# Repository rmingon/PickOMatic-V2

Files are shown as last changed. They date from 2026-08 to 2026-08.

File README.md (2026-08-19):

# PickOMatic V2

> **Place faster. Place smarter. The open-source motion controller that turns your pick-and-place ambitions into production reality.**

<p align="center">
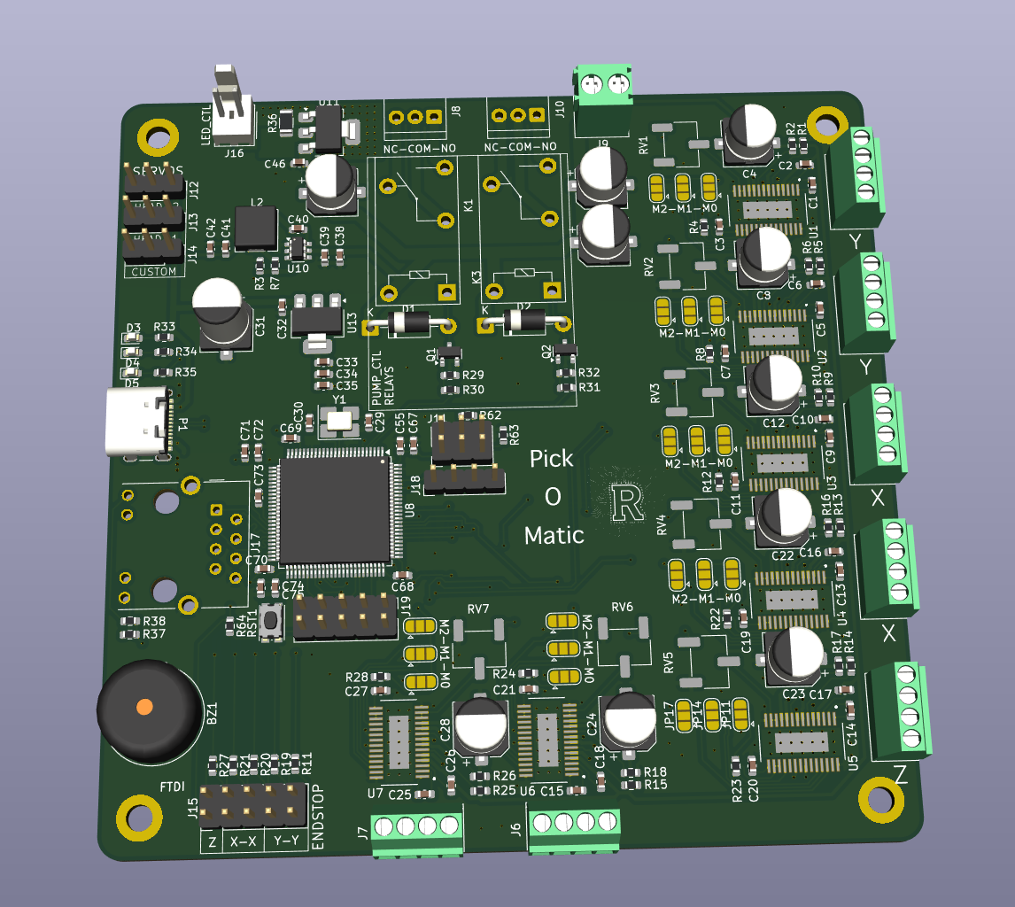
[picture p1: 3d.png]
PickOMatic V2 board, 3D render
  
</p>

<p align="center">
  
  
  
  
</p>

---

**PickOMatic V2** is a professional-grade, all-in-one motion control board designed from the ground up for desktop pick-and-place machines. It is the second generation of the [PickOMatic](https://github.com/rmingon/PickOMatic) motion controller, rebuilt around a modern 32-bit **RISC-V** microcontroller with native **Ethernet** and **USB-C** connectivity.

One board drives the entire machine: gantry, picker heads, nozzles, vacuum, lighting and feedback, with no shields, no breakout spaghetti and no compromises.

## Highlights

- **RISC-V power** : WCH **CH32V317VCT6** (QingKe 32-bit RISC-V core, LQFP-100), a massive leap over the 8-bit ATmega2560 of V1
- **7 stepper channels** : on-board **DRV8825** drivers for the XY gantry, Z axis and auxiliary picker-head axes, each with per-channel microstepping selection (M0/M1/M2 solder jumpers) and current trim
- **Ethernet on board** : integrated PHY with RJ45 magjack (HR911105A) for fast, reliable G-code streaming over the network
- **USB-C** : modern connectivity for setup, control and firmware workflows
- **Vacuum and pneumatics** : dedicated relay outputs (NC-COM-NO) for the vacuum pump and pneumatic accessories
- **3 servo outputs** : independent nozzle height / rotation control per picker head
- **5 endstop inputs** : dedicated limit-switch inputs for X, Y and Z homing (dual X and dual Y supported)
- **Inspection lighting** : dedicated LED control output for camera lighting
- **Operator feedback** : on-board buzzer and status LEDs
- **Expansion ready** : I²C bus, custom headers, FTDI UART header, SWD debug port and BOOT jumpers
- **Clean power architecture** : single 12 V input with on-board buck converters (TPS562200) and LDO rails for logic

## What's new in V2

| | PickOMatic V1 | **PickOMatic V2** |
|---|---|---|
| Microcontroller | ATmega2560 @ 16 MHz (8-bit AVR) | **CH32V317VCT6 (32-bit RISC-V)** |
| Host link | USB-UART (CH340C) | **Native USB-C + Ethernet (RJ45)** |
| Stepper channels | 8 | 7 x DRV8825 with per-axis microstep jumpers |
| Debug / programming | AVR-ISP | **SWD + FTDI UART + BOOT jumpers** |
| Networking | None | **On-board Ethernet PHY + magjack** |

## Board overview

| PCB layout | Schematic |
|:---:|:---:|
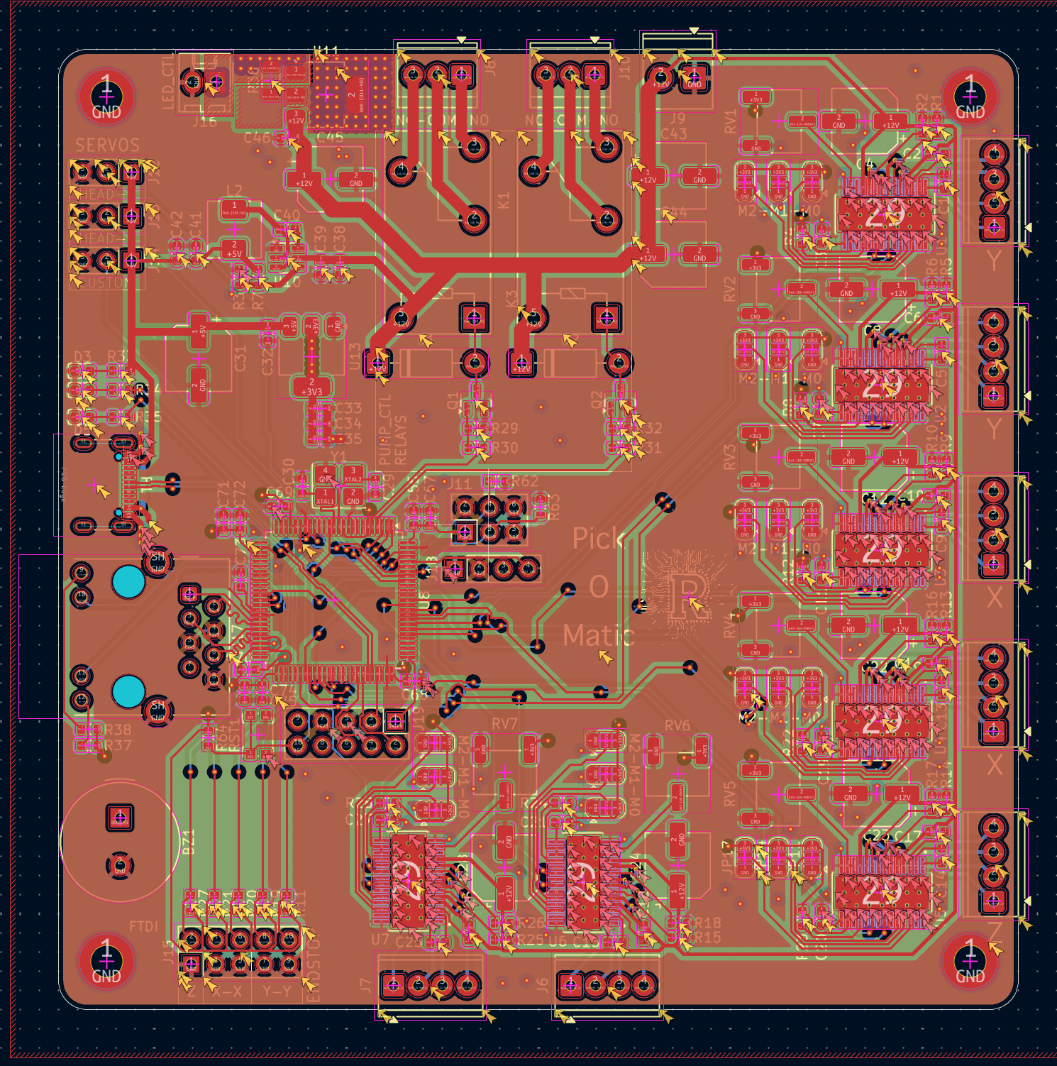
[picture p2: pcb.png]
PCB layout
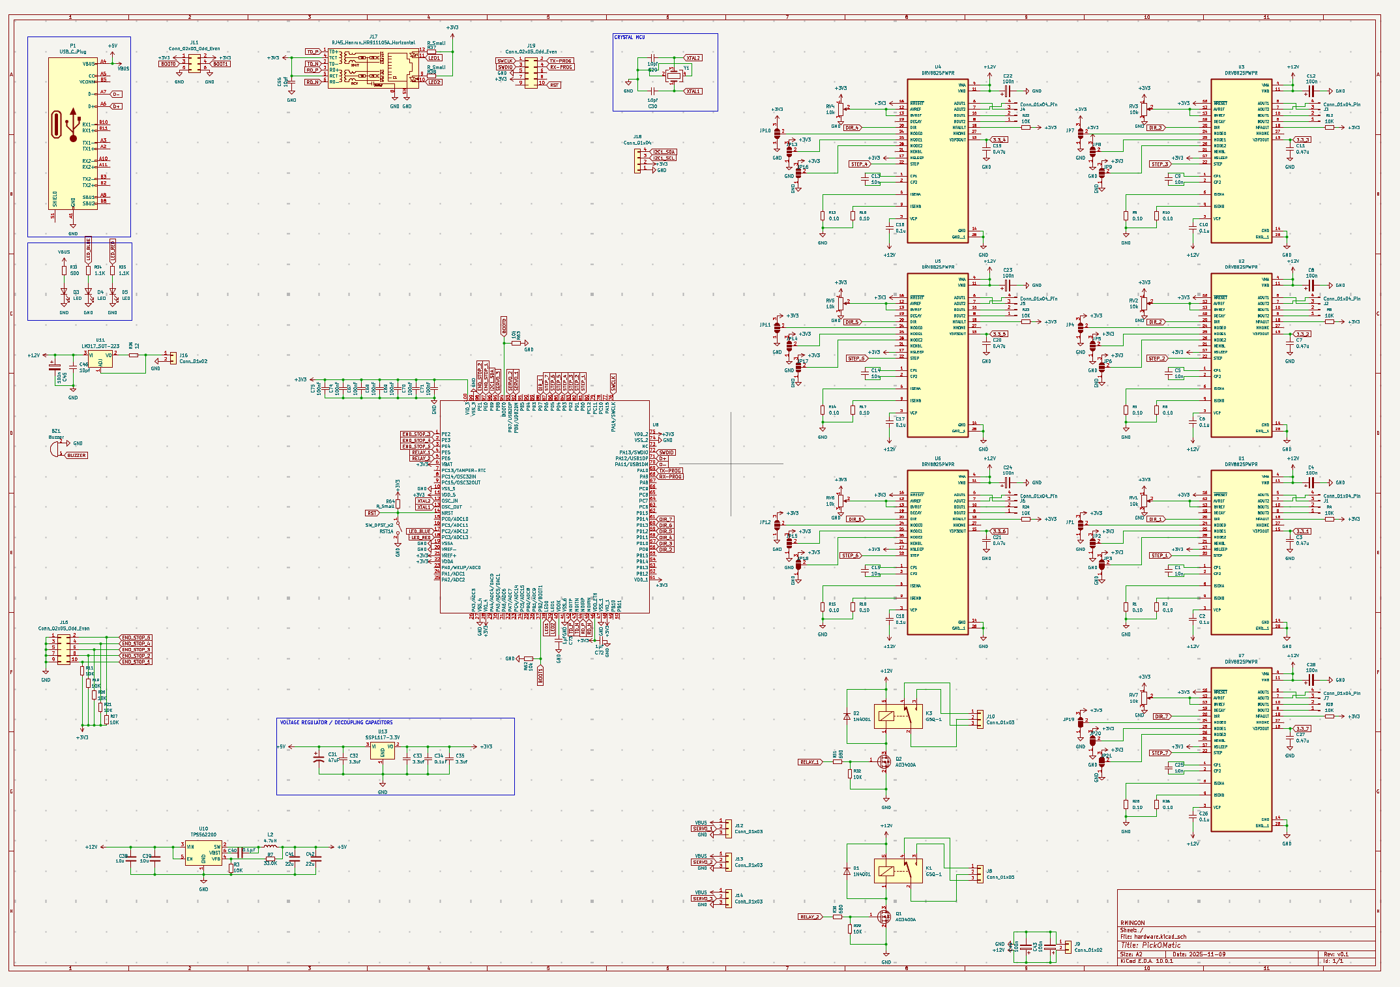
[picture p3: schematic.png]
Schematic
|  |  |

## Specifications

| Subsystem | Detail |
|---|---|
| MCU | WCH CH32V317VCT6, 32-bit RISC-V, LQFP-100, external crystal |
| Motion | 7 x DRV8825 stepper drivers (STEP/DIR), microstepping via M0/M1/M2 solder jumpers, current trim potentiometers |
| Axes | Dual-Y and dual-X gantry support, Z axis, auxiliary picker-head channels |
| Endstops | 5 inputs (Z, X-X, Y-Y) on a dedicated header |
| Servos | 3 PWM outputs for nozzle actuation |
| Pneumatics | Relay outputs with NC-COM-NO terminals for vacuum pump control |
| Lighting | Dedicated LED_CTL output for inspection lighting |
| Connectivity | USB-C, 10M Ethernet (RJ45 HR911105A), I²C expansion, FTDI UART |
| Debug | SWD (SWCLK/SWDIO), BOOT0/BOOT1 jumpers, reset button |
| Feedback | Buzzer, status LEDs |
| Power input | 12 V DC via screw terminal |
| Power rails | 12 V motor rail, 5 V and 3.3 V logic rails (TPS562200 buck converters + LDOs) |
| Form factor | 4-corner mounting holes, screw-terminal I/O on board edges |

## Repository structure

```
PickOMatic-V2/
├── hardware/               # KiCad project (schematic + PCB)
│   ├── hardware.kicad_pro
│   ├── hardware.kicad_sch
│   └── hardware.kicad_pcb
├── 3d.png                  # 3D render of the assembled board
├── pcb.png                 # PCB layout view
├── schematic.png           # Full schematic
├── LICENSE                 # CERN-OHL-S v2
└── README.md
```

## Getting started

1. **Clone** the repository
   ```bash
   git clone https://github.com/rmingon/PickOMatic-V2.git
   ```
2. **Open** `hardware/hardware.kicad_pro` in [KiCad](https://www.kicad.org/) (version 8 or later recommended)
3. **Review** the schematic and PCB, then export Gerbers and the BOM for your fab house
4. **Assemble**, set the DRV8825 current limits, configure microstepping with the solder jumpers, and connect your motors, endstops, servos and vacuum pump
5. **Flash** your firmware via SWD or the FTDI/BOOT bootloader path, and start placing parts

## Related projects

- [PickOMatic (V1)](https://github.com/rmingon/PickOMatic) : the original ATmega2560-based motion controller this board evolved from

## Contributing

Issues and pull requests are welcome. If you build a machine around PickOMatic V2, share it: photos, firmware ports and feeder designs all help the project grow.

## License

This project is open-source hardware, released under the **CERN Open Hardware Licence Version 2, Strongly Reciprocal (CERN-OHL-S-2.0)**.

You may use, study, modify, manufacture and distribute this design, provided that any modified versions are released under the same licence and that source is made available. See [LICENSE](LICENSE) for the full text.

Copyright © 2026 [rmingon](https://github.com/rmingon)

---

<p align="center"><i>PickOMatic V2, because your components deserve to be placed with confidence.</i></p>

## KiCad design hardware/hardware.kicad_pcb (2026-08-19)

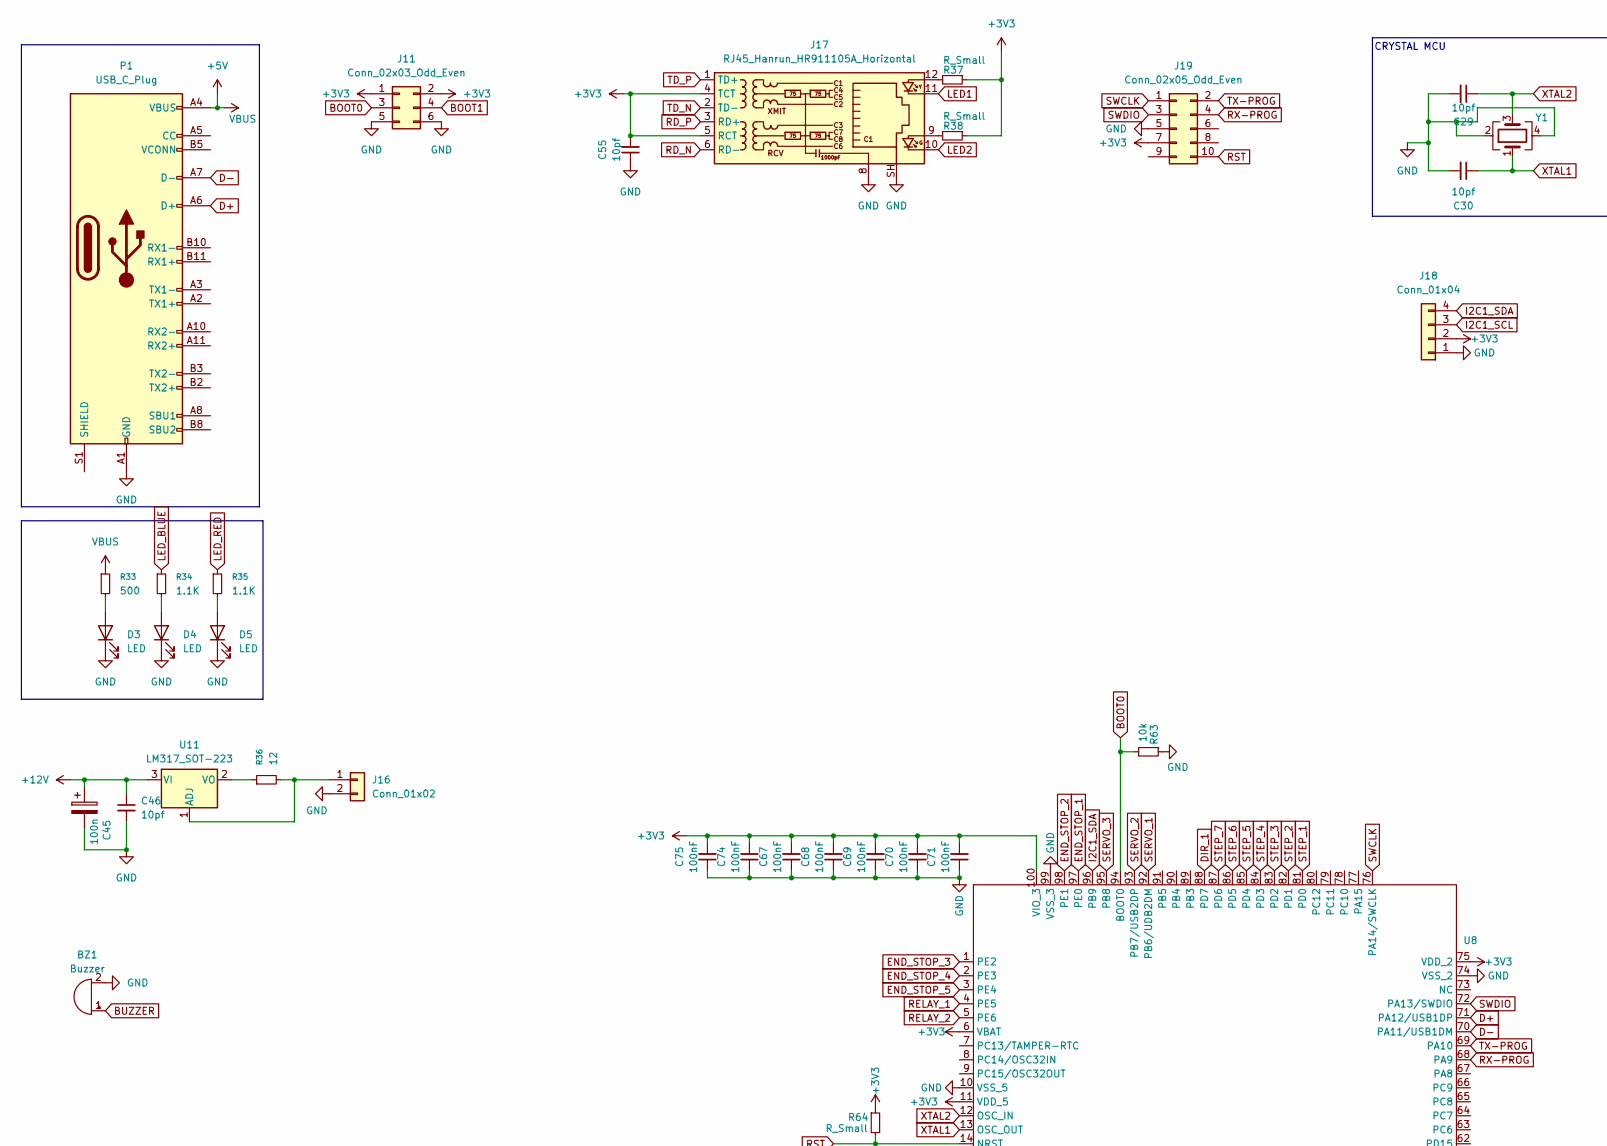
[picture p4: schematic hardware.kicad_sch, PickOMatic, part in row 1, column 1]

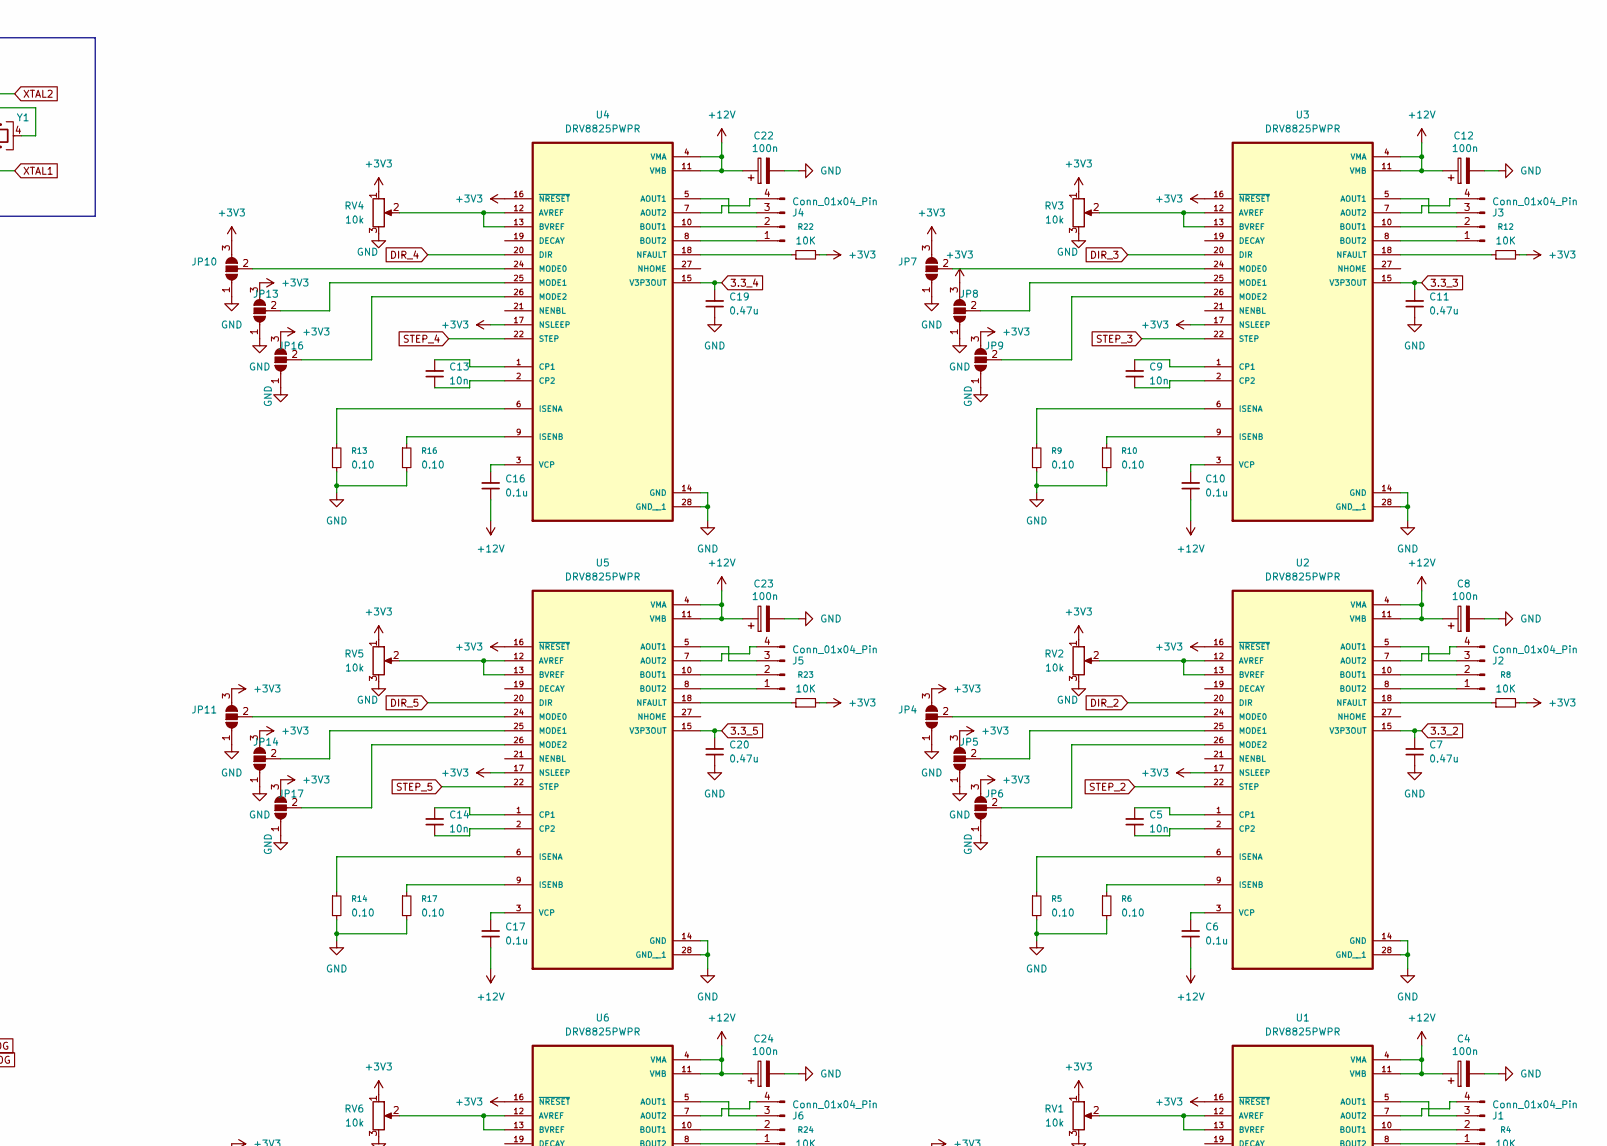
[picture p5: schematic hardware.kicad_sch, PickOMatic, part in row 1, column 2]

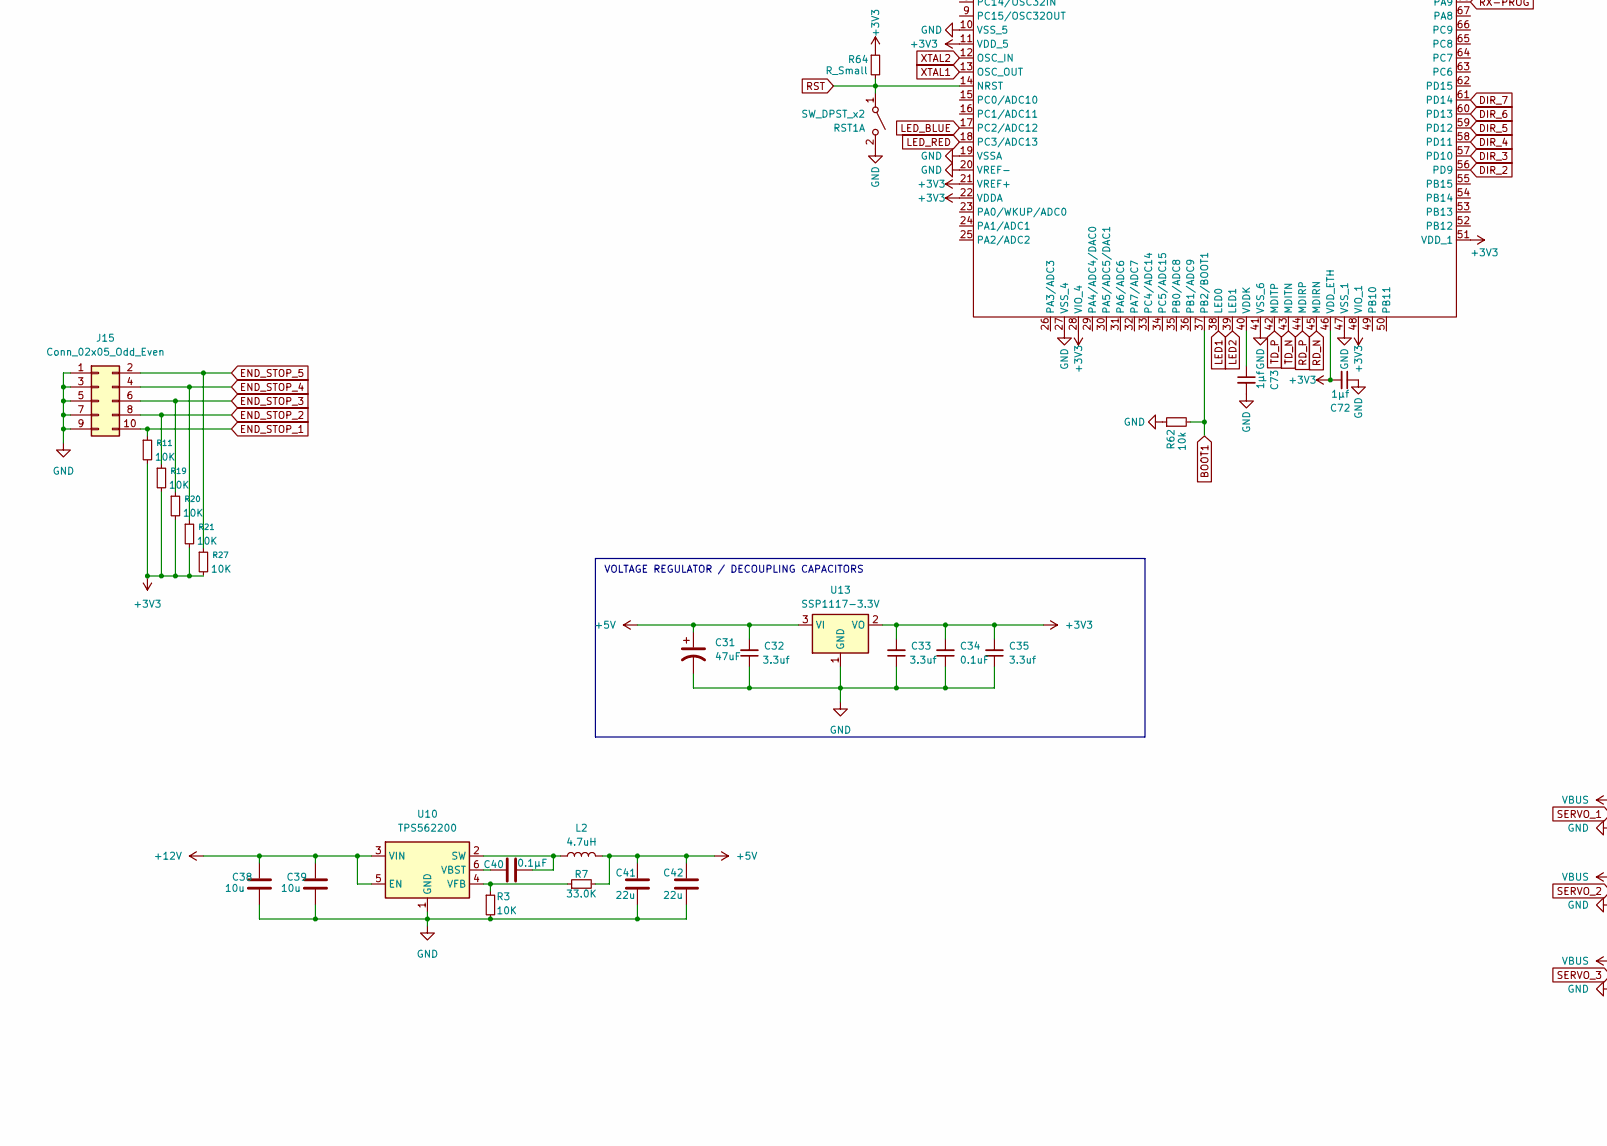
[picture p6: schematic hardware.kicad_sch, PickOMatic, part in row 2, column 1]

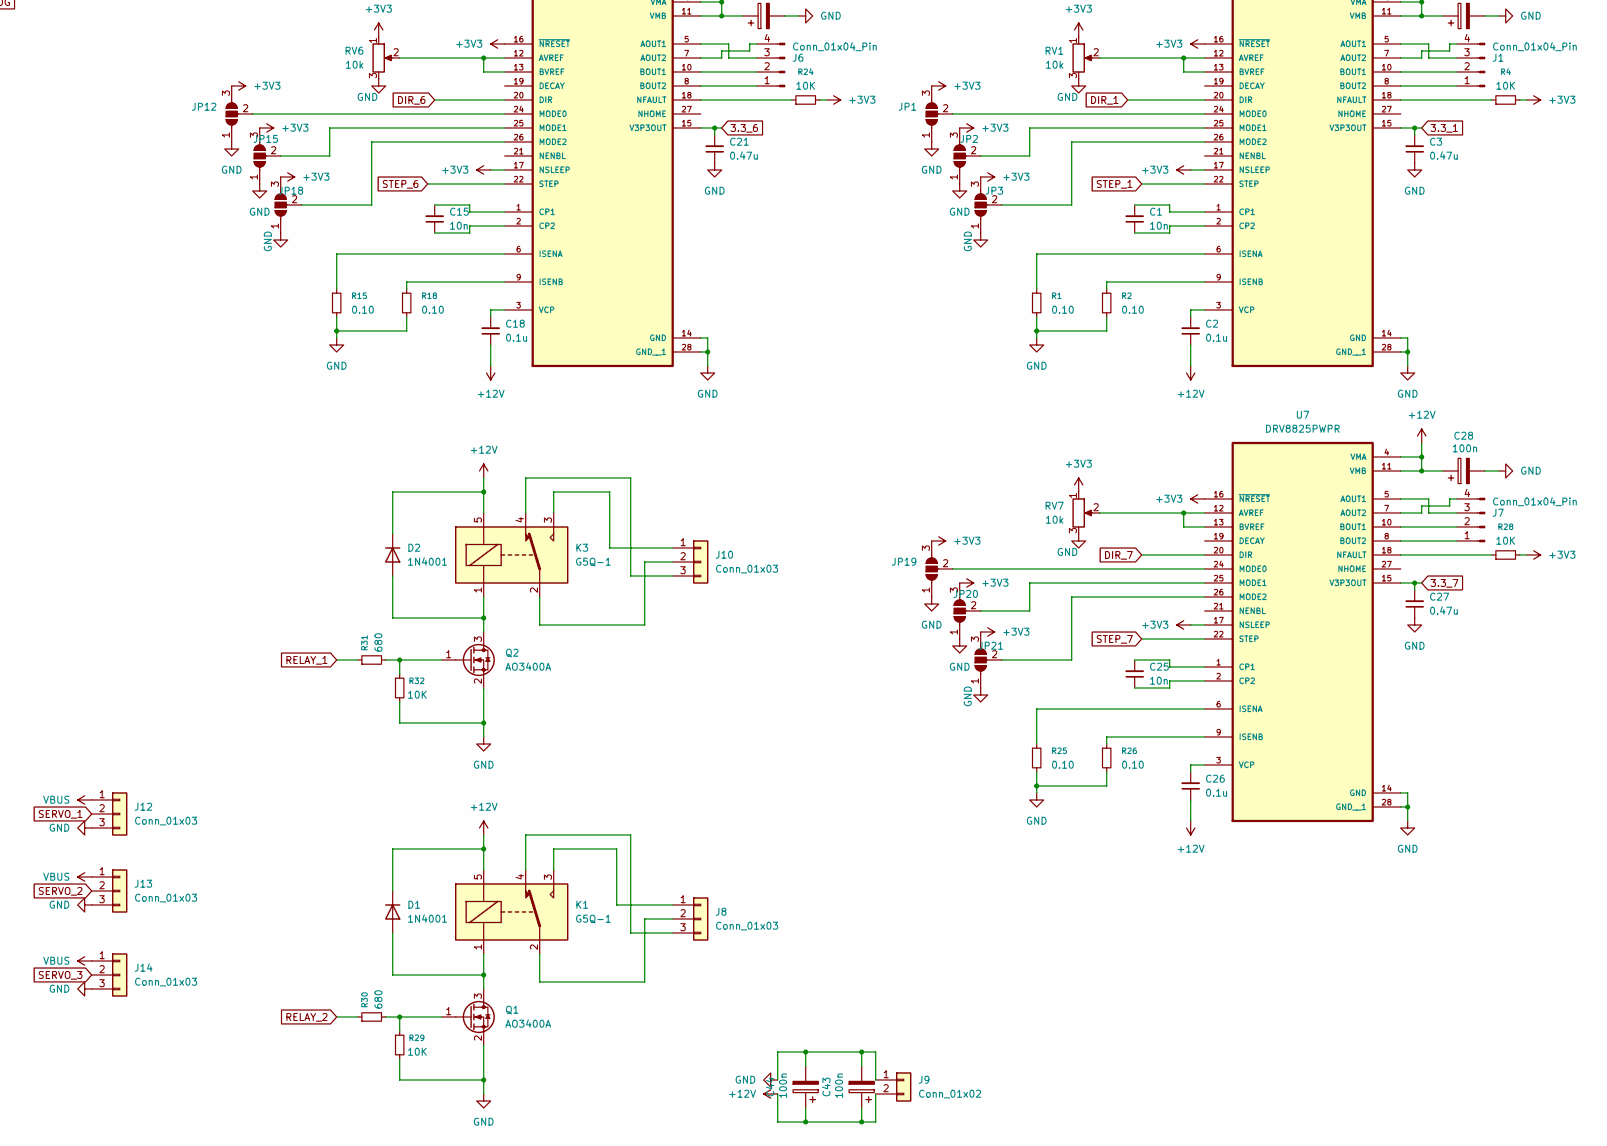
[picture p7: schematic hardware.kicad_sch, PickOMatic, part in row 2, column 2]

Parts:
BZ1: Buzzer; Buzzer_TDK_PS1240P02BT_D12.2mm_H6.5mm
C1, C5, C9, C13, C14, C15, C25: 10n; C_0603_1608Metric
C2, C6, C10, C16, C17, C18, C26: 0.1u; C_0603_1608Metric
C3, C7, C11, C19, C20, C21, C27: 0.47u; C_0603_1608Metric
C4, C8, C12, C22, C23, C24, C28, C43, C44, C45: 100n; CP_Elec_6.3x5.7
C29, C30, C46, C55: 10pf; C_0603_1608Metric; LCSC C106245
C31: 47uF; CP_Elec_6.3x9.9; LCSC C3032930
C32, C33, C35: 3.3uf; C_0603_1608Metric; LCSC C51412
C34: 0.1uF; C_0603_1608Metric; LCSC C14663
C38, C39: 10u; C_0603_1608Metric; LCSC C1691
C40: 0.1µF; C_0603_1608Metric; LCSC C6119867
C41, C42: 22u; C_0603_1608Metric; LCSC C6119867
C67, C68, C69, C70, C71, C74, C75: 100nF; C_0603_1608Metric; LCSC C106245
C72, C73: 1µf; C_0603_1608Metric; LCSC C106245
D1, D2: 1N4001; D_DO-41_SOD81_P10.16mm_Horizontal
D3, D4, D5: LED; LED_0603_1608Metric
J1, J2, J3, J4, J5, J6, J7: Conn_01x04_Pin; TerminalBlock_Phoenix_MPT-0,5-4-2.54_1x04_P2.54mm_Horizontal
J8, J10: Conn_01x03; TerminalBlock_TE_282834-3_1x03_P2.54mm_Horizontal
J9: Conn_01x02; TerminalBlock_Phoenix_PT-1,5-2-3.5-H_1x02_P3.50mm_Horizontal
J11: Conn_02x03_Odd_Even; PinHeader_2x03_P2.54mm_Vertical
J12, J13, J14: Conn_01x03; PinHeader_1x03_P2.54mm_Vertical
J15, J19: Conn_02x05_Odd_Even; PinHeader_2x05_P2.54mm_Vertical
J16: Conn_01x02; Molex_KK-254_AE-6410-02A_1x02_P2.54mm_Vertical
J17: RJ45_Hanrun_HR911105A_Horizontal
J18: Conn_01x04; PinHeader_1x04_P2.54mm_Vertical
JP1, JP2, JP3, JP4, JP5, JP6, JP7, JP8, JP9, JP10, JP11, JP12, JP13, JP14, JP15, JP16, JP17, JP18, JP19, JP20, JP21: SolderJumper_3_Open; SolderJumper-3_P1.3mm_Open_RoundedPad1.0x1.5mm
K1, K3: G5Q-1; Relay_SPDT_Omron-G5Q-1
L2: 4.7uH; L_Chilisin_BMRA00050520; LCSC C3002619
P1: USB_C_Plug; USB_C_Receptacle_GCT_USB4105-xx-A_16P_TopMnt_Horizontal
Q1, Q2: AO3400A; SOT-23
R1, R2, R5, R6, R9, R10, R13, R14, R15, R16, R17, R18, R25, R26: 0.10; R_0603_1608Metric
R3: 10K; R_0603_1608Metric; LCSC C25804
R4, R8, R11, R12, R19, R20, R21, R22, R23, R24, R27, R28, R29, R32: 10K; R_0603_1608Metric
R7: 33.0K; R_0603_1608Metric; LCSC C4216
R30, R31: 680; R_0603_1608Metric
R33: 500; R_0603_1608Metric
R34, R35: 1.1K; R_0603_1608Metric
R36: 12; R_1206_3216Metric
R37, R38, R64: R_Small; R_0603_1608Metric
R62, R63: 10k; R_0603_1608Metric
RST1: SW_DPST_x2; SW_Push_1P1T_NO_CK_KMR2
RV1, RV2, RV3, RV4, RV5, RV6, RV7: 10k; Potentiometer_Bourns_3269W_Vertical
U1, U2, U3, U4, U5, U6, U7: DRV8825PWPR; IC_TPS61196PWPRQ1
U8: LQFP-100_14x14mm_P0.5mm
U10: TPS562200; SOT-23-6; LCSC C49757
U11: LM317_SOT-223; SOT-223-3_TabPin2
U13: SSP1117-3.3V; SOT-223-3_TabPin2; LCSC C277892
Y1: Crystal_GND24; Crystal_SMD_3225-4Pin_3.2x2.5mm_HandSoldering

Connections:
3.3_1: C3.2, U1.15 (V3P3OUT)
3.3_2: C7.2, U2.15 (V3P3OUT)
3.3_3: C11.2, U3.15 (V3P3OUT)
3.3_4: C19.2, U4.15 (V3P3OUT)
3.3_5: C20.2, U5.15 (V3P3OUT)
3.3_6: C21.2, U6.15 (V3P3OUT)
3.3_7: C27.2, U7.15 (V3P3OUT)
+3V3: C33.2, C34.2, C35.2, C55.2, C67.2, C68.2, C69.2, C70.2, C71.2, C72.2, C74.2, C75.2, J11.1, J11.2, J17.4 (TCT), J17.5 (RCT), J18.2, J19.7, JP1.3 (B), JP2.3 (B), JP3.3 (B), JP4.3 (B), JP5.3 (B), JP6.3 (B), JP7.3 (B), JP8.3 (B), JP9.3 (B), JP10.3 (B), JP11.3 (B), JP12.3 (B), JP13.3 (B), JP14.3 (B), JP15.3 (B), JP16.3 (B), JP17.3 (B), JP18.3 (B), JP19.3 (B), JP20.3 (B), JP21.3 (B), R4.2, R8.2, R11.2, R12.2, R19.2, R20.2, R21.2, R22.2, R23.2, R24.2, R27.2, R28.2, R37.1, R38.1, R64.1, RV1.1, RV2.1, RV3.1, RV4.1, RV5.1, RV6.1, RV7.1, U1.16 (~NRESET), U1.17 (NSLEEP), U2.16 (~NRESET), U2.17 (NSLEEP), U3.16 (~NRESET), U3.17 (NSLEEP), U4.16 (~NRESET), U4.17 (NSLEEP), U5.16 (~NRESET), U5.17 (NSLEEP), U6.16 (~NRESET), U6.17 (NSLEEP), U7.16 (~NRESET), U7.17 (NSLEEP), U8.6 (VBAT), U8.11 (VDD_5), U8.21 (VREF+), U8.22 (VDDA), U8.28 (VIO_4), U8.46 (VDD_ETH), U8.48 (VIO_1), U8.51 (VDD_1), U8.75 (VDD_2), U8.100 (VIO_3), U13.2 (VO)
+5V: C31.1, C32.2, C41.1, C42.1, J12.1, J13.1, J14.1, L2.2, P1.A4 (VBUS), P1.A9 (VBUS), P1.B4 (VBUS), P1.B9 (VBUS), R7.2, R33.1, U13.3 (VI)
+12V: C2.1, C4.1, C6.1, C8.1, C10.1, C12.1, C16.1, C17.1, C18.1, C22.1, C23.1, C24.1, C26.1, C28.1, C38.1, C39.1, C43.1, C44.1, C45.1, C46.1, D1.1 (K), D2.1 (K), J9.2, K1.5, K3.5, U1.4 (VMA), U1.11 (VMB), U2.4 (VMA), U2.11 (VMB), U3.4 (VMA), U3.11 (VMB), U4.4 (VMA), U4.11 (VMB), U5.4 (VMA), U5.11 (VMB), U6.4 (VMA), U6.11 (VMB), U7.4 (VMA), U7.11 (VMB), U10.3 (VIN), U10.5 (EN), U11.3 (VI)
BOOT0: J11.3, R63.2, U8.94 (BOOT0)
BOOT1: J11.4, R62.2, U8.37 (PB2/BOOT1)
BUZZER: BZ1.1 (+)
D+: P1.A6 (D+), U8.71 (PA12/USB1DP)
D-: P1.A7 (D-), U8.70 (PA11/USB1DM)
DIR_1: U1.20 (DIR), U8.88 (PD7)
DIR_2: U2.20 (DIR), U8.56 (PD9)
DIR_3: U3.20 (DIR), U8.57 (PD10)
DIR_4: U4.20 (DIR), U8.58 (PD11)
DIR_5: U5.20 (DIR), U8.59 (PD12)
DIR_6: U6.20 (DIR), U8.60 (PD13)
DIR_7: U7.20 (DIR), U8.61 (PD14)
END_STOP_1: J15.10, R11.1, U8.97 (PE0)
END_STOP_2: J15.8, R19.1, U8.98 (PE1)
END_STOP_3: J15.6, R20.1, U8.1 (PE2)
END_STOP_4: J15.4, R21.1, U8.2 (PE3)
END_STOP_5: J15.2, R27.1, U8.3 (PE4)
GND: BZ1.2 (-), C3.1, C4.2, C7.1, C8.2, C11.1, C12.2, C19.1, C20.1, C21.1, C22.2, C23.2, C24.2, C27.1, C28.2, C29.2, C30.2, C31.2, C32.1, C33.1, C34.1, C35.1, C38.2, C39.2, C41.2, C42.2, C43.2, C44.2, C45.2, C46.2, C55.1, C67.1, C68.1, C69.1, C70.1, C71.1, C72.1, C73.2, C74.1, C75.1, D3.1 (K), D4.1 (K), D5.1 (K), J9.1, J11.5, J11.6, J12.3, J13.3, J14.3, J15.1, J15.3, J15.5, J15.7, J15.9, J16.2, J17.8, J17.SH, J18.1, J19.5, JP1.1 (A), JP2.1 (A), JP3.1 (A), JP4.1 (A), JP5.1 (A), JP6.1 (A), JP7.1 (A), JP8.1 (A), JP9.1 (A), JP10.1 (A), JP11.1 (A), JP12.1 (A), JP13.1 (A), JP14.1 (A), JP15.1 (A), JP16.1 (A), JP17.1 (A), JP18.1 (A), JP19.1 (A), JP20.1 (A), JP21.1 (A), P1.A1 (GND), P1.A12 (GND), P1.B1 (GND), P1.B12 (GND), Q1.2 (S), Q2.2 (S), R1.2, R2.2, R3.2, R5.2, R6.2, R9.2, R10.2, R13.2, R14.2, R15.2, R16.2, R17.2, R18.2, R25.2, R26.2, R29.2, R32.2, R62.1, R63.1, RST1.2 (B), RV1.3, RV2.3, RV3.3, RV4.3, RV5.3, RV6.3, RV7.3, U1.14 (GND), U1.28 (GND__1), U2.14 (GND), U2.28 (GND__1), U3.14 (GND), U3.28 (GND__1), U4.14 (GND), U4.28 (GND__1), U5.14 (GND), U5.28 (GND__1), U6.14 (GND), U6.28 (GND__1), U7.14 (GND), U7.28 (GND__1), U8.10 (VSS_5), U8.19 (VSSA), U8.20 (VREF-), U8.27 (VSS_4), U8.41 (VSS_6), U8.47 (VSS_1), U8.74 (VSS_2), U8.99 (VSS_3), U10.1 (GND), U13.1 (GND), Y1.2, Y1.4
I2C1_SCL: J18.3
I2C1_SDA: J18.4, U8.96 (PB9)
LED1: J17.11, U8.38 (LED0)
LED2: J17.10, U8.39 (LED1)
LED_BLUE: R34.1, U8.17 (PC2/ADC12)
LED_RED: R35.1, U8.18 (PC3/ADC13)
unnamed: D1.2 (A), K1.1, Q1.3 (D)
unnamed: D2.2 (A), K3.1, Q2.3 (D)
unnamed: D3.2 (A), R33.2
unnamed: D4.2 (A), R34.2
unnamed: D5.2 (A), R35.2
unnamed: J1.1, U1.8 (BOUT2)
unnamed: J1.2, U1.10 (BOUT1)
unnamed: J1.3, U1.5 (AOUT1)
unnamed: J1.4, U1.7 (AOUT2)
unnamed: J2.1, U2.8 (BOUT2)
unnamed: J2.2, U2.10 (BOUT1)
unnamed: J2.3, U2.5 (AOUT1)
unnamed: J2.4, U2.7 (AOUT2)
unnamed: J3.1, U3.8 (BOUT2)
unnamed: J3.2, U3.10 (BOUT1)
unnamed: J3.3, U3.5 (AOUT1)
unnamed: J3.4, U3.7 (AOUT2)
unnamed: J4.1, U4.8 (BOUT2)
unnamed: J4.2, U4.10 (BOUT1)
unnamed: J4.3, U4.5 (AOUT1)
unnamed: J4.4, U4.7 (AOUT2)
unnamed: J5.1, U5.8 (BOUT2)
unnamed: J5.2, U5.10 (BOUT1)
unnamed: J5.3, U5.5 (AOUT1)
unnamed: J5.4, U5.7 (AOUT2)
unnamed: J6.1, U6.8 (BOUT2)
unnamed: J6.2, U6.10 (BOUT1)
unnamed: J6.3, U6.5 (AOUT1)
unnamed: J6.4, U6.7 (AOUT2)
unnamed: J7.1, U7.8 (BOUT2)
unnamed: J7.2, U7.10 (BOUT1)
unnamed: J7.3, U7.5 (AOUT1)
unnamed: J7.4, U7.7 (AOUT2)
unnamed: J8.1, K1.3
unnamed: J8.2, K1.2
unnamed: J8.3, K1.4
unnamed: J10.1, K3.3
unnamed: J10.2, K3.2
unnamed: J10.3, K3.4
unnamed: J16.1, R36.2, U11.1 (ADJ)
unnamed: J17.9, R38.2
unnamed: J17.12, R37.2
unnamed: JP1.2 (C), U1.24 (MODE0)
unnamed: JP2.2 (C), U1.25 (MODE1)
unnamed: JP3.2 (C), U1.26 (MODE2)
unnamed: JP4.2 (C), U2.24 (MODE0)
unnamed: JP5.2 (C), U2.25 (MODE1)
unnamed: JP6.2 (C), U2.26 (MODE2)
unnamed: JP7.2 (C), U3.24 (MODE0)
unnamed: JP8.2 (C), U3.25 (MODE1)
unnamed: JP9.2 (C), U3.26 (MODE2)
unnamed: JP10.2 (C), U4.24 (MODE0)
unnamed: JP11.2 (C), U5.24 (MODE0)
unnamed: JP12.2 (C), U6.24 (MODE0)
unnamed: JP13.2 (C), U4.25 (MODE1)
unnamed: JP14.2 (C), U5.25 (MODE1)
unnamed: JP15.2 (C), U6.25 (MODE1)
unnamed: JP16.2 (C), U4.26 (MODE2)
unnamed: JP17.2 (C), U5.26 (MODE2)
unnamed: JP18.2 (C), U6.26 (MODE2)
unnamed: JP19.2 (C), U7.24 (MODE0)
unnamed: JP20.2 (C), U7.25 (MODE1)
unnamed: JP21.2 (C), U7.26 (MODE2)
unnamed: Q1.1 (G), R29.1, R30.2
unnamed: Q2.1 (G), R31.2, R32.1
unnamed: RV1.2, U1.12 (AVREF), U1.13 (BVREF)
unnamed: C1.2, U1.1 (CP1)
unnamed: C1.1, U1.2 (CP2)
unnamed: R1.1, U1.6 (ISENA)
unnamed: R2.1, U1.9 (ISENB)
unnamed: R4.1, U1.18 (NFAULT)
unnamed: C2.2, U1.3 (VCP)
unnamed: RV2.2, U2.12 (AVREF), U2.13 (BVREF)
unnamed: C5.2, U2.1 (CP1)
unnamed: C5.1, U2.2 (CP2)
unnamed: R5.1, U2.6 (ISENA)
unnamed: R6.1, U2.9 (ISENB)
unnamed: R8.1, U2.18 (NFAULT)
unnamed: C6.2, U2.3 (VCP)
unnamed: RV3.2, U3.12 (AVREF), U3.13 (BVREF)
unnamed: C9.2, U3.1 (CP1)
unnamed: C9.1, U3.2 (CP2)
unnamed: R9.1, U3.6 (ISENA)
unnamed: R10.1, U3.9 (ISENB)
unnamed: R12.1, U3.18 (NFAULT)
unnamed: C10.2, U3.3 (VCP)
unnamed: RV4.2, U4.12 (AVREF), U4.13 (BVREF)
unnamed: C13.2, U4.1 (CP1)
unnamed: C13.1, U4.2 (CP2)
unnamed: R13.1, U4.6 (ISENA)
unnamed: R16.1, U4.9 (ISENB)
unnamed: R22.1, U4.18 (NFAULT)
unnamed: C16.2, U4.3 (VCP)
unnamed: RV5.2, U5.12 (AVREF), U5.13 (BVREF)
unnamed: C14.2, U5.1 (CP1)
unnamed: C14.1, U5.2 (CP2)
unnamed: R14.1, U5.6 (ISENA)
unnamed: R17.1, U5.9 (ISENB)
unnamed: R23.1, U5.18 (NFAULT)
unnamed: C17.2, U5.3 (VCP)
unnamed: RV6.2, U6.12 (AVREF), U6.13 (BVREF)
unnamed: C15.2, U6.1 (CP1)
unnamed: C15.1, U6.2 (CP2)
unnamed: R15.1, U6.6 (ISENA)
unnamed: R18.1, U6.9 (ISENB)
unnamed: R24.1, U6.18 (NFAULT)
unnamed: C18.2, U6.3 (VCP)
unnamed: RV7.2, U7.12 (AVREF), U7.13 (BVREF)
unnamed: C25.2, U7.1 (CP1)
unnamed: C25.1, U7.2 (CP2)
unnamed: R25.1, U7.6 (ISENA)
unnamed: R26.1, U7.9 (ISENB)
unnamed: R28.1, U7.18 (NFAULT)
unnamed: C26.2, U7.3 (VCP)
unnamed: C73.1, U8.40 (VDDK)
unnamed: C40.2, L2.1, U10.2 (SW)
unnamed: C40.1, U10.6 (VBST)
unnamed: R3.1, R7.1, U10.4 (VFB)
unnamed: R36.1, U11.2 (VO)
RD_N: J17.6 (RD-), U8.45 (MDIRN)
RD_P: J17.3 (RD+), U8.44 (MDIRP)
RELAY_1: R31.1, U8.4 (PE5)
RELAY_2: R30.1, U8.5 (PE6)
RST: J19.10, R64.2, RST1.1 (A), U8.14 (NRST)
RX-PROG: J19.4, U8.68 (PA9)
SERVO_1: J12.2, U8.92 (PB6/UDB2DM)
SERVO_2: J13.2, U8.93 (PB7/USB2DP)
SERVO_3: J14.2, U8.95 (PB8)
STEP_1: U1.22 (STEP), U8.81 (PD0)
STEP_2: U2.22 (STEP), U8.82 (PD1)
STEP_3: U3.22 (STEP), U8.83 (PD2)
STEP_4: U4.22 (STEP), U8.84 (PD3)
STEP_5: U5.22 (STEP), U8.85 (PD4)
STEP_6: U6.22 (STEP), U8.86 (PD5)
STEP_7: U7.22 (STEP), U8.87 (PD6)
SWCLK: J19.1, U8.76 (PA14/SWCLK)
SWDIO: J19.3, U8.72 (PA13/SWDIO)
TD_N: J17.2 (TD-), U8.43 (MDITN)
TD_P: J17.1 (TD+), U8.42 (MDITP)
TX-PROG: J19.2, U8.69 (PA10)
XTAL1: C30.1, U8.13 (OSC_OUT), Y1.1
XTAL2: C29.1, U8.12 (OSC_IN), Y1.3

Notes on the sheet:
CRYSTAL MCU
VOLTAGE REGULATOR / DECOUPLING CAPACITORS

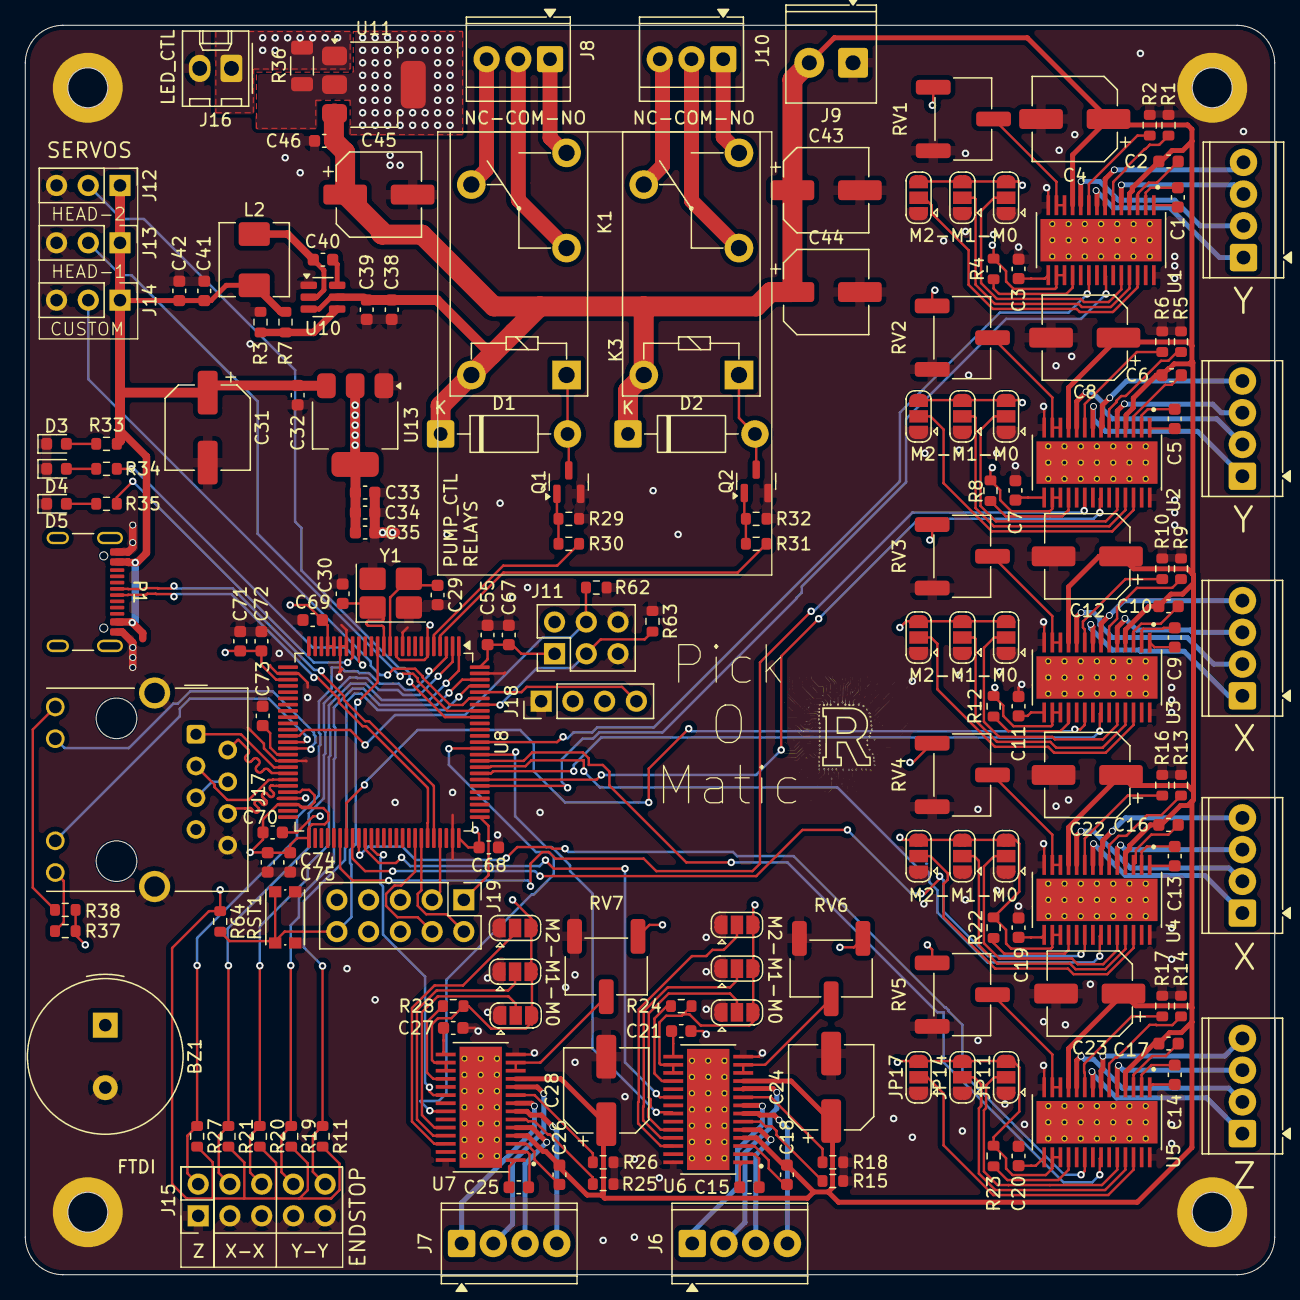
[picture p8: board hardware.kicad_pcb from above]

Board: 4 copper layers, 100.0 x 100.0 mm, 167 parts (0 on the bottom side), 174 nets.

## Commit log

2026-08-18 commit PCB
    [hardware.kicad_pcb, hardware.kicad_sch]
2026-08-19 vbus to 3.3 on DRV
    [hardware.kicad_pcb, hardware.kicad_sch]
2026-08-19 finish PCB
    [hardware.kicad_pcb, hardware.kicad_sch]

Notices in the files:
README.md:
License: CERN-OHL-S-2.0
